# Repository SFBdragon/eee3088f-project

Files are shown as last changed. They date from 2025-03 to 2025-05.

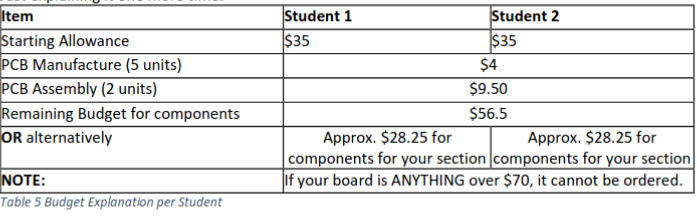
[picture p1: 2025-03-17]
notes/eee3088f-project/resources/budget-table.png

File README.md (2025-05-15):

# EEE3088F Project

> Power board for a micro-mouse designed for EEE3088F Engineering Design Principles @ UCT

#### Authors

_Team #69_
- Shaun Beautement
- Adedamola Yusuff

### Project Description

The board aims to meet the following requirements:
- Operate up to 4 motors bidirectionally 
    - Controls 2x brushed DC motors which could each draw 200mA @ 4.2V
    - Controls 2x motors at 500mA each.
- Monitor the battery using an INA219
- Charge the battery from USB supply
- Two charging modes the battery: IBAT = 200mA, or 600mA ±100mA
- Integrate USB C and get 9V out of the USB Host
- Provide 2x high-side external load switching with 5V regulated supply, drawing at most 1A each
- Provide a 3V3 5% accuracy (300mA max) and 5V Out 5% accuracy (1.5A max)
- Provide an ON/OFF switch.
    - OFF state: battery draw <30uA.
    - ON state: can provide your robot peak current of 2A.

The board is designed to be printable with PCBA for most components for under $70 with JLCPCB. As-is, the design costs about $50, not including the JST and 2x16 connector, which was provided to us.

The board is shaped to fit to and interface with
- [Justin Pead](https://ebe.uct.ac.za/department-electrical-engineering/contacts/justin-pead)'s micro-mouse (2025 version)
- a [1s1p LiPo battery](https://www.robotics.org.za/802540)
- a USB C cable (USB v2 and v3 should work) for charging

### Software

The schematic and PCB design is drafted in [KiCAD](https://www.kicad.org/), with metadata included for JLCPCB using [KiCAD JLCPCB Tools](https://github.com/Bouni/kicad-jlcpcb-tools).

Some prototype simulations in [LTspice](https://www.analog.com/en/resources/design-tools-and-calculators/ltspice-simulator.html) are included in `ltspice/`.

Some working notes are included under `notes/` and can be viewed in [Obsidian](https://obsidian.md/). But are best unseen.

### Usage Warning

It is not recommended to use this design as-is, as the board is incapable of delivering regulated supply voltages and driving motors.

With this design:
- There was a short from the buck-boosts' (TPS63020) VIN pins to GND, seemingly through the IC (without having powered the board). The cause is unclear at time of writing.
- The motor drivers were not operational. The cause is unclear at time of writing, and may have been a defieciency in the testing methodology.
- There are some capacitors with incorrect footprints.
- The USB C port is too far back on the board.

These have not been corrected for at time of writing, largely to preserve the state of the design for project submission.

### License 

CERN Open Hardware Licence Version 2 - Permissive

See [LICENSE.md](./LICENSE.md)

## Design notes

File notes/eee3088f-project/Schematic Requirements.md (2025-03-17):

+ A JST PH 2mm pin pitch connector for the battery. The battery will be tucked away between the motherboard PCB and the processor PCB.
+ A 2x16 (2.54mm pin pitch) pin header: It needs to fit onto the MM’s motherboard 2x16 2.54mm pitch connector with the correct pinout. Hint: be sure to pay attention to the alignment of the pins
+ The maximum dimensions for your board are 82 x 60 for it to fit under the motherboard PCB. Please note this even though JLC allows larger.
+ The shape of the board is an important consideration: If your board extends to any of the drill holes on the MB, your power board needs to use them for securing your PCB as the weight of the PCB will be too much for the connector alone.
+ The Motherboard dimensions arc radius is 80mm and the connectors centre is 15.3mm from the apex of the arc.

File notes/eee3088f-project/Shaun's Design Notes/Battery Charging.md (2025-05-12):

• Charge the battery from the 9V input pin (listed in the power pinout table).

• Have two charging modes for a higher and lower charging current for the battery (200mA, and approximately 600mA ±100mA from the battery perspective.

---

Input: 9V

Output: $V_{BAT}$ iff not charging, else nada

$I_{BAT}$ = 200mA - 600mA ($\pm 100$mA)

| Part | VIN MAX | IBAT MAX | Usable | Reason | JLC |
| --- | --- | --- | --- | --- | --- |
| TP5000 | | | No | Buck, Tiny Rs | |
| [TP4056](https://jlcpcb.com/api/file/downloadByFileSystemAccessId/8588879072461508608) | 8V | 1A | Yes | Lots of features! | [link](https://jlcpcb.com/partdetail/17264-TP4056_42ESOP8/C16581) |
| TP4057 | | 0.5A ! | No | | |
| [TP4054](https://www.laskakit.cz/user/related_files/tp4054.pdf) | 9V | 0.8A | Yes | | [link](https://jlcpcb.com/partdetail/33539-TP4054_42SOT25R/C32574) |
| MAX8903 | | | No | Low stock, linear instead of buck (too much power dis.) | |
| [FM4057](https://jlcpcb.com/api/file/downloadByFileSystemAccessId/8588918019694845952) | | | Yes | Loader fee! | [link](https://jlcpcb.com/partdetail/Shenzhen_FumanElec-FM4057S52/C841288) |
| [SLM6305](https://jlcpcb.com/partdetail/solaic-SLM6305/C711584) | | | No | Buck, Tiny Rs | [link](https://jlcpcb.com/partdetail/solaic-SLM6305/C711584) |
| [TP5100](https://jlcpcb.com/api/file/downloadByFileSystemAccessId/8588884095233769472) | | | No | Buck, Tiny Rs | [link](https://jlcpcb.com/partdetail/solaic-SLM6305/C711584) |
| BQ24610 | | | No | Buck, Tiny Rs, Seriously overkill (2x costs $1.7) | |
| | | | | | |
![[Pasted image 20250424195714.png]]
XL1059 (buck converter IC, basic)
+FM407S42 (linear battery management IC for charging control)
+MOSFET switching the resistance

Ignore all of this, I went with something else...

SLM6305 calculations:

$R_{s,eff,fast} = \frac{0.0667}{I_{BAT}} =  \frac{0.0667}{0.6} = 111m\Omega$
$R_{s,eff,slow} = \frac{0.0667}{I_{BAT}} = \frac{0.0667}{0.2} = 333.5m\Omega$

We need more resistance when FAST is LOW.

MOSFET gate and source are roughly 4.2V
Requires logic low to turn on.
So P channel MOSFET

$R_{s,always} = R_{s,eff,fast} - R_{DS,on} = 0.111 - (0.048||R_{s,bypass})$
$R_{s,bypass} = R_{s,eff,slow} - R_{s,always} = 0.3335 - R_{s,always}$

$R_{s,always} = 70.4m\Omega$
$R_{s,bypass} = 263.1m\Omega$

We need to invert the input.

$R_{s,slow} = R_{s,eff,slow} - R_{DS,on} =$

---

Buck converter

https://www.ti.com/lit/ds/symlink/tps5430.pdf?ts=1742809000146

$$L_{MIN} = \frac{V_{OUT(MAX)}(V_{IN(MAX)}-V_{OUT})}{V_{IN(MAX)} K_{IND} I_{OUT} F_{SW}} = \frac{5(9-5)}{9*0.3*0.8*500000} = 18.5\mu H$$

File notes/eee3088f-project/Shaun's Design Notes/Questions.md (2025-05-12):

Should we worry about rotations

---

Must the INA219 be powered even when the system is "off" 

---

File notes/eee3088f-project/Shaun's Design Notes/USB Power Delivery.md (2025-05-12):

• Integrate USB C and get 9V out of the USB Host

---

https://www.usb.org/sites/default/files/USB%20Type-C%20Spec%20R2.0%20-%20August%202019.pdf

USB PD 
https://jlcpcb.com/parts/2nd/Power_Management_(PMIC)/USB_PD_1639

Relevant pins:

| Pin No | Name | Purpose |
| --- | --- | --- |
| 13 | `FAST_CHARGE_CTRL` | Logic-level signal for fast charge ON/OFF |
| 14 | `BATTERY` | Connect to VBAT+ |
| 19 | `GND` | Connect to GND |
| 22 | `HV` | Connect to 9V from USB PD |

CH224K
https://jlcpcb.com/partdetail/wch_jiangsu_Qin_heng-CH224K/C970725
??????????
https://www.laskakit.cz/user/related_files/ch224ds1.pdf
YESSSSSSSSSSSSSSSSS

ACTUALLY NEEDS MAX12 AND THERE'S NONE AVAILABLE
https://jlcpcb.com/partdetail/Injoinic-IP2721/C603176
https://jlcpcb.com/api/file/downloadByFileSystemAccessId/8588893818120769536
IP2721
Can request 9V directly without uC

https://www.ti.com/lit/ds/symlink/tusb320.pdf?ts=1745478480336
Not sure if this actually does what I need

https://jlcpcb.com/api/file/downloadByFileSystemAccessId/8589839603521269760
same deal

https://www.nxp.com/docs/en/data-sheet/PTN5150A.pdf
?

https://www.st.com/resource/en/datasheet/stusb4500.pdf
Definitely can do what I need.
$1.78 https://jlcpcb.com/partdetail/Stmicroelectronics-STUSB4500QTR/C2678061
NOT BY DEFAULT

https://www.ti.com/lit/ds/symlink/tps25730.pdf?ts=1742514233405
also seems stupidly overkill

**FUSB302B**
https://jlcpcb.com/partdetail/Onsemi-FUSB302BMPX/C132291
not passively usable?

USB C connector
**NEED TO BUY**

Battery connector
https://www.robotics.org.za/JST-PH-2P-90?search=jst
no need to buy

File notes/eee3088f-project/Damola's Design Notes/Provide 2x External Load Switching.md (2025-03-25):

Provide 2x External Load Switching at 1A each (High Side connected to your 5V)

## Thoughts:
I'm struggling to even interpret this

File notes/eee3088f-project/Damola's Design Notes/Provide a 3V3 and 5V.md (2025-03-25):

Provide a 3V3 5% accuracy (300mA max) and 5V Out 5% accuracy (1.5A max)

## Thoughts:
Just use voltage regulators, no?
Indeed, no.

## Decisions:

$V_{out}=V_{ref}\times(1+\frac{R_{3}}{R_{4}})$ 
$\frac{V_{out}}{V_{ref}}-1=\frac{R_{A}}{R_{B}}$

$V_{ref}=0.6V$ (typical)

$V_{out1}=5V$
$V_{out2}=3V3$

### Resistor Options for 5V (Boost Converter):

$\frac{V_{out1}}{0.6}-1=\frac{R_{3}}{R_{4}}$
$\frac{5}{0.6}-1=\frac{R_{3}}{R_{4}}$
$7.33=\frac{R_{3}}{R_{4}}$

$R_{4}=1000\Omega$
$R_3=6800\Omega+510\Omega$  $(7.31)$

$R_{4}=1300\Omega$
$R_3=9100\Omega+510\Omega$  $(7.39)$

$R_{4}=1800\Omega$
$R_3=13000\Omega+200\Omega$  $(7.33)$

The one above looks very good but will the $200\Omega$ survive the current?
$R_4=1800\Omega$ 
$R_3=11000\Omega+2200\Omega$  $(7.33)$ is better. (This became $R_3$ and $R_7$)

## Resistor Options for 5V (Buck-Boost Converter):

$R_1=R_2\times(\frac{V_{OUT}}{V_{FB}}-1)$
$\frac{R_1}{R_2}=(\frac{V_{OUT}}{V_{FB}}-1)$
$V_{FB}=0.5V$
$V_{OUT}=5V$
$\frac{R_1}{R_2}=\frac{5}{0.5}-1$
$\frac{R_1}{R_2}=9$
$R_1=(4.3\times10^{x})+(4.7\times10^{x})$
$R_2=1.0\times10^{x}$

The current through the resistive divider should be about 100 times greater than the
current into the FB pin.

The typical current into the FB pin is 0.01μA and the voltage across the resistor between
FB and GND, R2, is typically 500 mV. Based on these two values, the recommended value for R2 should be lower than 500kΩ (Because $500k\Omega=\frac{500mV}{0.01μA\times100}$).

Therefore, we can choose:
$R_2=100k$
and $R_1=430k\Omega+470k\Omega$

## Choosing an inductor for the 5V Buck-Boost converter

The larger the inductor value, the smaller the inductor ripple current and the lower the conduction losses of the converter. Conversely, larger inductor values cause a slower load transient response

The datasheet tells me what to choose.

0.63

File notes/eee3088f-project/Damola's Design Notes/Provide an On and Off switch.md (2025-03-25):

Provide an ON/OFF switch. OFF state: battery draw <30uA. ON state: can provide your robot peak current of 2A. The switch needs to shut down 5V and 3V3.

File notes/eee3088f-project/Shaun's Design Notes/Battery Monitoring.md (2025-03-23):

Place an INA219 for monitoring the battery on the I2C Bus and configure it correctly with respect to the hardware (cannot have BOTH A0 AND A1 on GND)

---

TODO

| Pin No | Name | Purpose |
| --- | --- | --- |
| 16 | `I2C1_SCL`  | I2C communication with current/voltage/power monitor (clock) |
| 17 | `I2C1_SDA`  | I2C communication with current/voltage/power monitor (data)  |

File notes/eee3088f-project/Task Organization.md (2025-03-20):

### Shaun

• Place an INA219 for monitoring the battery on the I2C Bus and configure it correctly with
respect to the hardware (cannot have BOTH A0 AND A1 on GND)

• Have two charging modes for a higher and lower charging current for the battery (200mA, and approximately 600mA ±100mA from the battery perspective.

• Integrate USB C and get 9V out of the USB Host

• Charge the battery from the 9V input pin (listed in the power pinout table).

### Damola

• Operate up to 4 motors bidirectionally with the pins available to you (listed in the power pinout table). You will need to control 2x brushed DC motors which could each draw 200mA at the highest voltage of a 1S1P battery (the battery is further specified in the battery section).
The other 2x motors are for the auxiliary connection and need to operate 500mA each.

• Provide a 3V3 5% accuracy (300mA max) and 5V Out 5% accuracy (1.5A max)

• Provide an ON/OFF switch. OFF state: battery draw <30uA. ON state: can provide your robot peak current of 2A. The switch needs to shut down 5V and 3V3.

• Provide 2x External Load Switching at 1A each (High Side connected to your 5V)

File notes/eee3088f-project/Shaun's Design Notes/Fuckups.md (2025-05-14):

C4, C6, C8, C14, C15, C16, C18, C22
+3 others

| | C4 | C6 | C8 | C14 | C15  | C16  | C18  | C22 |
| --- | ---- | ---- | ---- | ----- | ---- | ---- | ---- | ----- |
| Cap | 10nF | 22uF | 10nF | 100nF | 22uF | 22u  | 22u  | 100nF |
| Board Foot | 0402 | 0805 | 0402 | 0603  | 0805 | 0805 | 0805 | 0603  |
| Ordered | 0805 | 0805 | 0805 | 0402  | 0603 | 0805 | 0805 | 0402  |

![[Pasted image 20250404172052.png]]

![[Pasted image 20250404171827.png]]

![[Pasted image 20250404171915.png]]

![[Pasted image 20250404171948.png]]

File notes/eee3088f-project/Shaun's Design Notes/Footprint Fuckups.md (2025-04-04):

C4, C8, C14, C15, C22

| | C4 | C8 | C14 | C15  | C22 |
| --- | ---- | ---- | ----- | ---- | ----- |
| Cap | 10nF | 10nF | 100nF | 22uF | 100nF |
| Board Foot | 0402 | 0402 | 0603  | 0805 | 0603  |
| Ordered | 0805 | 0805 | 0402  | 0603 | 0402  |

![[Pasted image 20250404172052.png]]

![[Pasted image 20250404171827.png]]

![[Pasted image 20250404171915.png]]

![[Pasted image 20250404171948.png]]

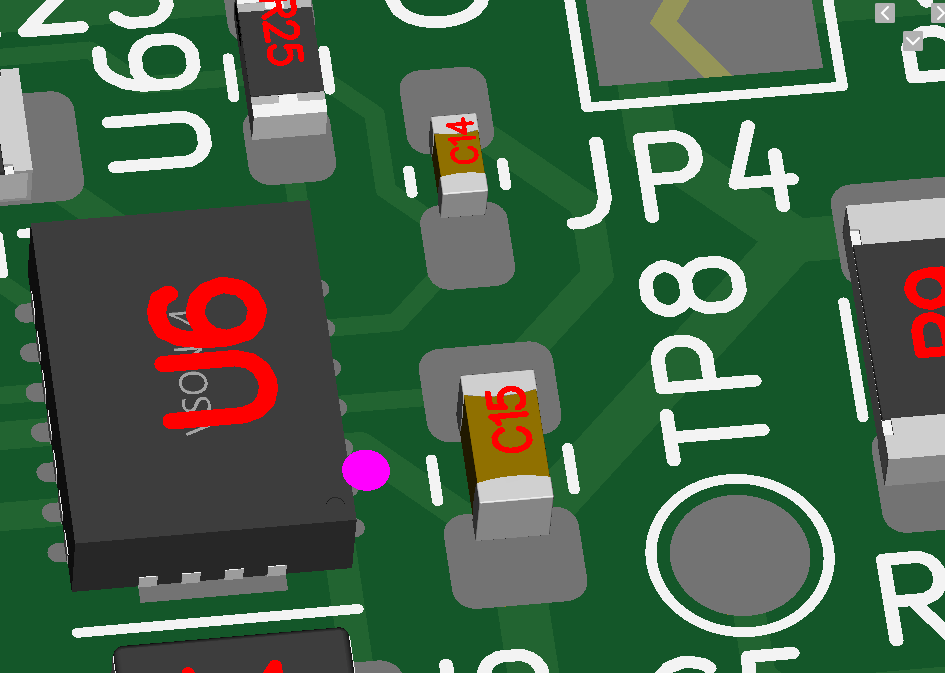
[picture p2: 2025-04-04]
notes/eee3088f-project/Shaun's Design Notes/resources/Pasted image 20250404171827.png

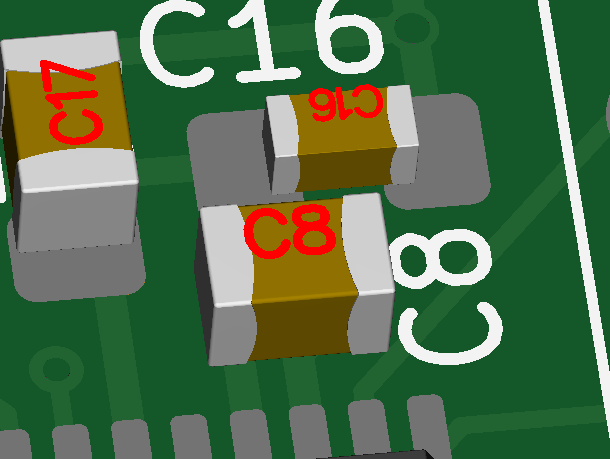
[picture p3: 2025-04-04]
notes/eee3088f-project/Shaun's Design Notes/resources/Pasted image 20250404171915.png

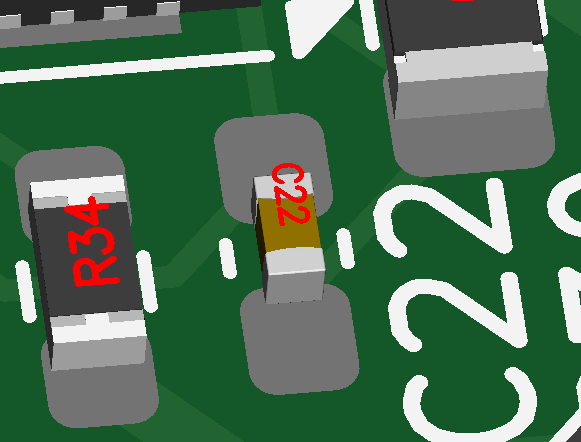
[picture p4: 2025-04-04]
notes/eee3088f-project/Shaun's Design Notes/resources/Pasted image 20250404172052.png

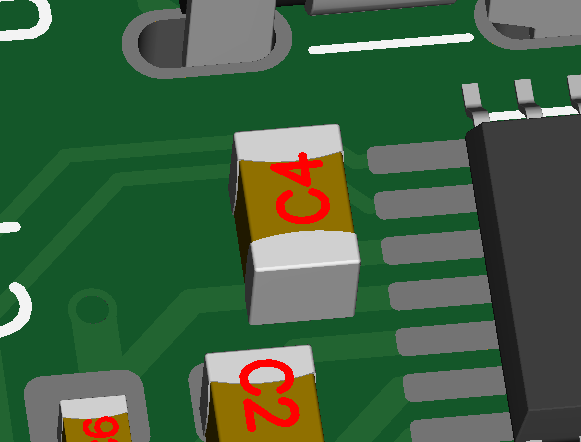
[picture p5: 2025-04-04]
notes/eee3088f-project/Shaun's Design Notes/resources/Pasted image 20250404171948.png

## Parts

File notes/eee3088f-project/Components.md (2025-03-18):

> Before we break this down, please note that when ordering the PCBs you will ONLY NEED TO POPULATE the USB-C connectors. To be clear, we will provide you with the pin headers and JST connectors described in the power subsystem section. You will still need to provide the footprint on your PCB but will not populate them in your BOM.

> Now to truly understand the difficulty of each task, you each have a total of $35 to have your board manufactured. That is 5x PCBs made @ $4, 2x PCBs populated @ $9.50 and then your component costs.

> `$13.5` is being used to manufacture a standard sized simple board. So, you have `$(35*2) – $13.5` worth of components on the sum of your board section. $56.5 on components. Pay attention to extended parts…

![[budget-table.png]]

Some special components we should probably strongly consider:
- H Bridge Drivers
- Voltage regulators (need Low Drop Out (LDO), consider linear (low efficiency, simply) vs switched-mode (higher efficiency, more complicated))

Shaun's components

| Component | Unit Cost | N |
| --- | --- | --- |
| | | |

Damola's components

| Component | Unit Cost | N |
| --- | --- | --- |
| | | |

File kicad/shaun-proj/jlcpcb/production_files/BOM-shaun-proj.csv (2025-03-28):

Comment | Designator | Footprint | LCSC | Quantity
INA219AxD | U3 | SOIC-8_3.9x4.9mm_P1.27mm | C138706 | 1
100n | C10 | C_0603_1608Metric_Pad1.08x0.95mm_HandSolder | C14663 | 1
AO3401A | Q1,Q3,Q6 | SOT-23 | C15127 | 3
10n | C9 | C_0402_1005Metric_Pad0.74x0.62mm_HandSolder | C15195 | 1
0.1µF | C14,C22 | C_0603_1608Metric_Pad1.08x0.95mm_HandSolder | C1525 | 2
TPS63020DSJR | U6,U8 | DAMOLA_VSON-14-1EP_3.4x4.4mm_P0.5mm_EP1.6x4.2mm | C15483 | 2
10u | C11 | C_0805_2012Metric_Pad1.18x1.45mm_HandSolder | C15850 | 1
TP4056-42-ESOP8 | U5 | SOIC-8-1EP_3.9x4.9mm_P1.27mm_EP2.41x3.3mm_ThermalVias | C16581 | 1
USB_C_Receptacle_USB2.0_16P | J1 | USB_C_Receptacle_G-Switch_GT-USB-7010ASV_MOD | C165948 | 1
0.01µF | C4,C8 | C_0402_1005Metric_Pad0.74x0.62mm_HandSolder | C1710 | 2
120k | R27 | R_0805_2012Metric_Pad1.20x1.40mm_HandSolder | C17436 | 1
180k | R24,R30 | R_0805_2012Metric_Pad1.20x1.40mm_HandSolder | C17501 | 2
10u | C3,C5 | C_0603_1608Metric_Pad1.08x0.95mm_HandSolder | C19702 | 2
AO3400A | Q2,Q4,Q5 | SOT-23 | C20917 | 3
1k | R14,R15,R17 | R_0603_1608Metric_Pad0.98x0.95mm_HandSolder | C21190 | 3
RED LED | D1 | LED_0603_1608Metric_Pad1.05x0.95mm_HandSolder | C2286 | 1
1M | R18,R23,R25,R3,R34,R5 | R_0603_1608Metric_Pad0.98x0.95mm_HandSolder | C22935 | 6
GREEN LED | D2,D4 | LED_0805_2012Metric_Pad1.15x1.40mm_HandSolder | C2297 | 2
3.3k | R12,R13,R20,R21 | R_0603_1608Metric_Pad0.98x0.95mm_HandSolder | C22978 | 4
3.9k | R7 | R_0603_1608Metric | C23018 | 1
6.8K | R1 | R_0603_1608Metric | C23212 | 1
SS14 | D5 | D_SMA | C2480 | 1
1 | R16,R29,R32,R33,R36,R8 | R_0805_2012Metric_Pad1.20x1.40mm_HandSolder | C25271 | 6
100m | R19,R26,R28,R31,R35,R9 | R_1206_3216Metric_Pad1.30x1.75mm_HandSolder | C25334 | 6
220u | C12,C13,C20 | CP_Elec_6.3x7.7 | C25503905 | 3
10k | R10,R11,R2,R6 | R_0603_1608Metric_Pad0.98x0.95mm_HandSolder | C25804 | 4
22u | L3 | L_SXN_SMDRI125 | C2924827 | 1
2.2µF | C17,C2 | C_0805_2012Metric_Pad1.18x1.45mm_HandSolder | C377773 | 2
1.5M | R22 | R_0603_1608Metric_Pad0.98x0.95mm_HandSolder | C4172 | 1
2k | R4 | R_0603_1608Metric | C4190 | 1
DRV8833PWPR | U4,U7 | HTSSOP-16-1EP_4.4x5mm_P0.65mm_EP3.4x5mm_Mask2.46x2.31mm_ThermalVias | C50506 | 2
1µH | L4,L5,L6 | L_1008_2520Metric_Pad1.43x2.20mm_HandSolder | C5179444 | 3
1u | C1 | C_0402_1005Metric_Pad0.74x0.62mm_HandSolder | C52923 | 1
22µF | C15,C16,C18,C6 | C_0805_2012Metric_Pad1.18x1.45mm_HandSolder | C59461 | 4
SW_SPDT | SW2 | SS-12D11G3R | C843362 | 1
CH224K | U1 | SSOP-10-1EP_3.9x4.9mm_P1mm_EP2.1x3.3mm_ThermalVias | C970725 | 1
TPS5430DDA | U2 | SOIC-8-1EP_3.9x4.9mm_P1.27mm_EP2.514x3.2mm | C9864 | 1

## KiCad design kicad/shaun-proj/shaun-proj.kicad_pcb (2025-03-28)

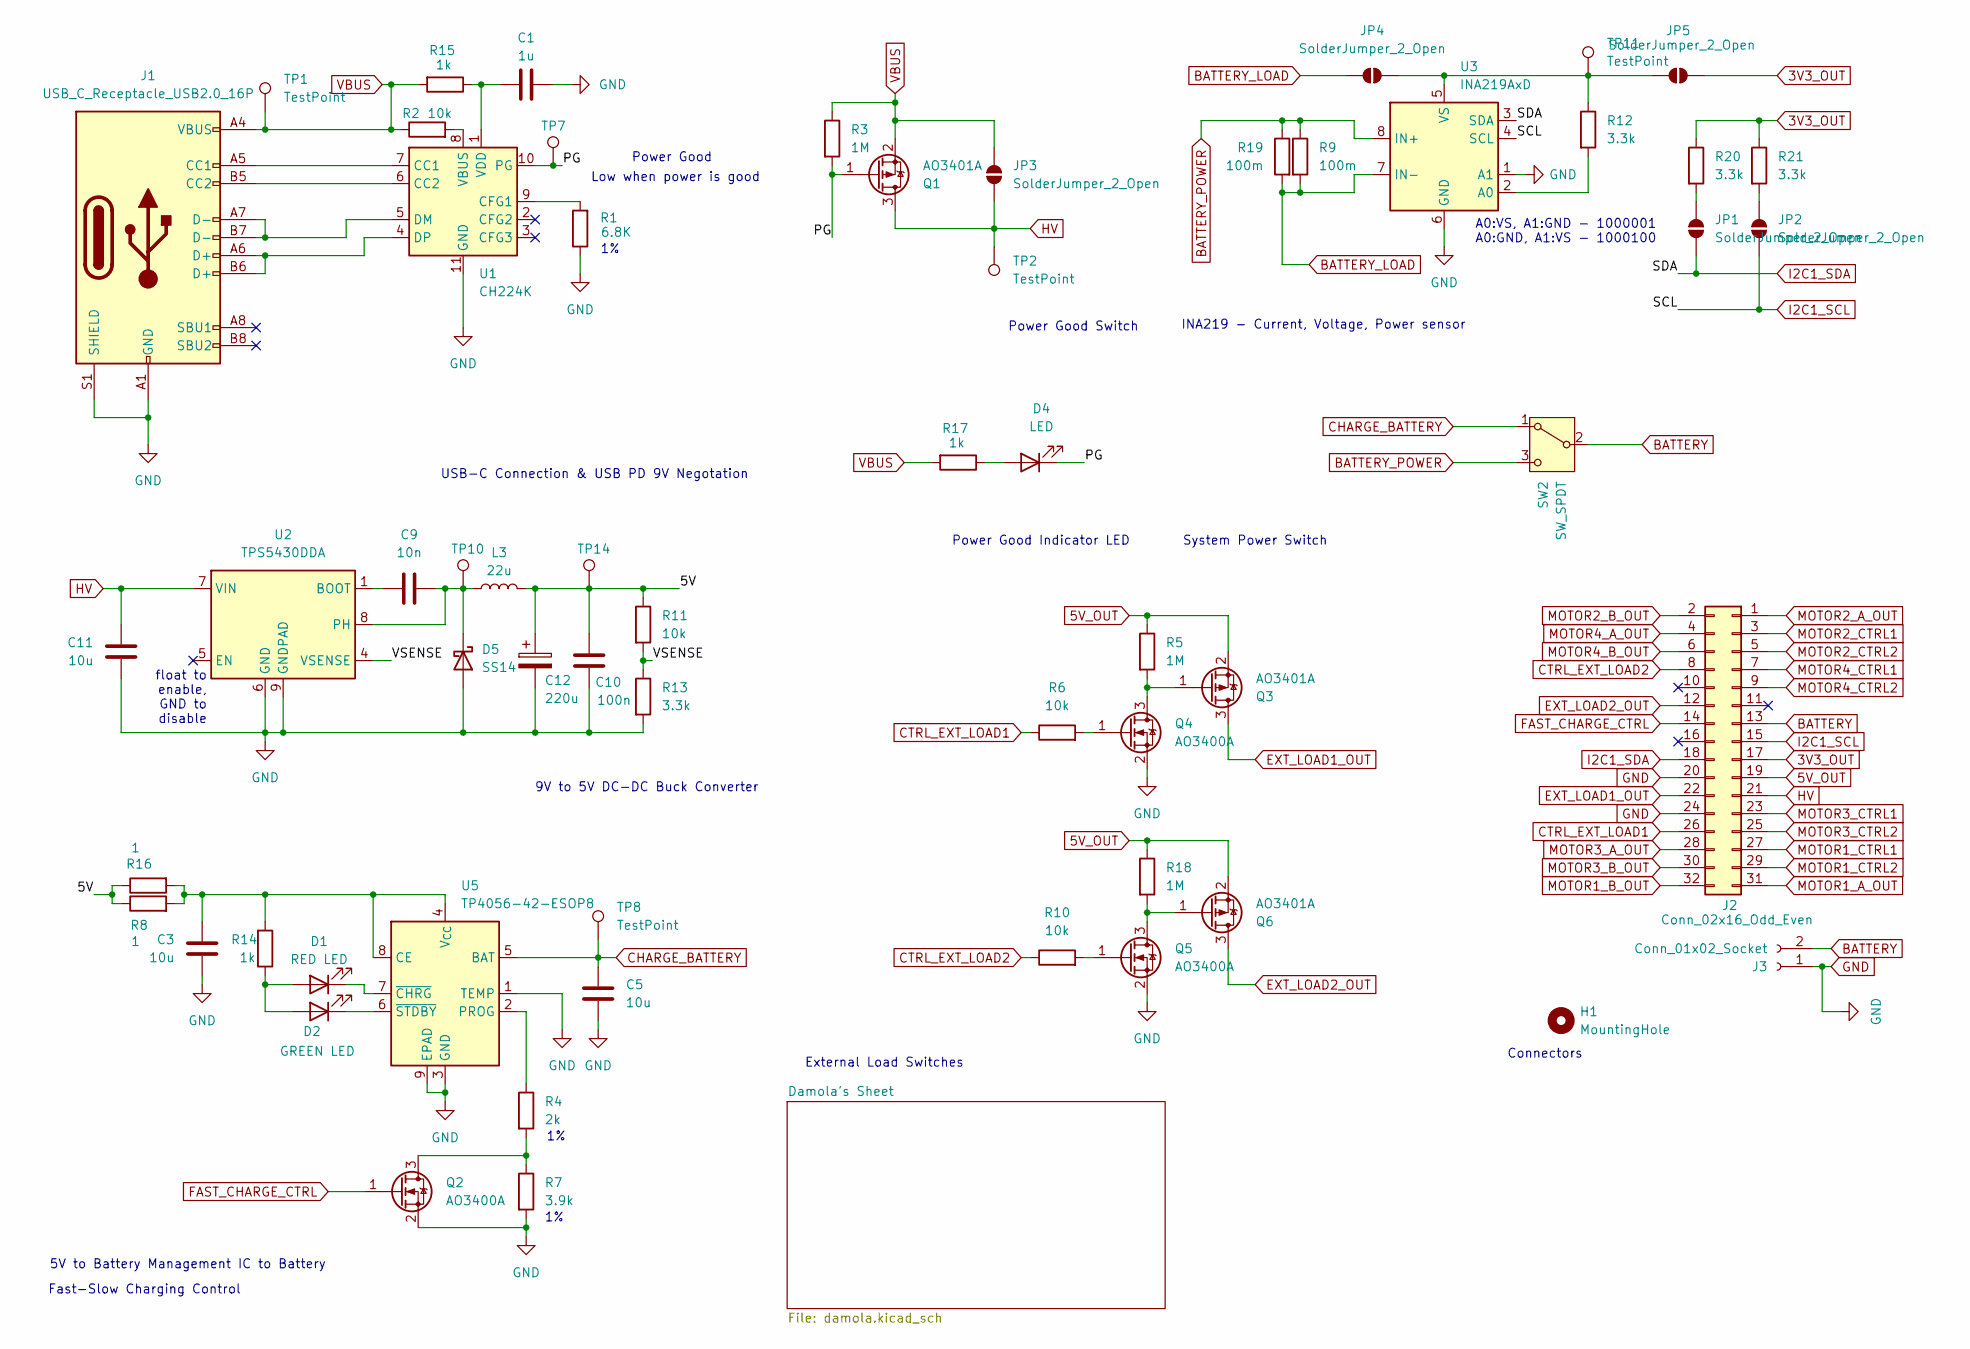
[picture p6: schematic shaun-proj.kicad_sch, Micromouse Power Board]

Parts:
C1: 1u; C_0402_1005Metric_Pad0.74x0.62mm_HandSolder
C3: 10u; C_0603_1608Metric_Pad1.08x0.95mm_HandSolder
C5: 10u; C_0603_1608Metric_Pad1.08x0.95mm_HandSolder; LCSC C19702
C9: 10n; C_0402_1005Metric_Pad0.74x0.62mm_HandSolder; LCSC C15195
C10: 100n; C_0603_1608Metric_Pad1.08x0.95mm_HandSolder
C11: 10u; C_0805_2012Metric_Pad1.18x1.45mm_HandSolder
C12: 220u; CP_Elec_6.3x7.7; LCSC C25503905
D1: RED LED; LED_0603_1608Metric_Pad1.05x0.95mm_HandSolder
D2: GREEN LED; LED_0805_2012Metric_Pad1.15x1.40mm_HandSolder
D4: LED; LED_0805_2012Metric_Pad1.15x1.40mm_HandSolder
D5: SS14; D_SMA
H1: MountingHole; MountingHole_3.2mm_M3
J1: USB_C_Receptacle_USB2.0_16P; USB_C_Receptacle_G-Switch_GT-USB-7010ASV_MOD; LCSC C165948
J2: Conn_02x16_Odd_Even; PinHeader_2x16_P2.54mm_Vertical
J3: Conn_01x02_Socket; JST_PH_S2B-PH-K_1x02_P2.00mm_Horizontal
JP1, JP2, JP3, JP4, JP5: SolderJumper_2_Open; SolderJumper-2_P1.3mm_Open_TrianglePad1.0x1.5mm
L3: 22u; L_SXN_SMDRI125
Q1, Q3, Q6: AO3401A; SOT-23; JLCPCB no C15127
Q2: AO3400A; SOT-23
Q4, Q5: AO3400A; SOT-23; LCSC C20917
R1: 6.8K; R_0603_1608Metric
R2, R6, R10, R11: 10k; R_0603_1608Metric_Pad0.98x0.95mm_HandSolder
R3, R5, R18: 1M; R_0603_1608Metric_Pad0.98x0.95mm_HandSolder
R4: 2k; R_0603_1608Metric
R7: 3.9k; R_0603_1608Metric
R8, R16: 1; R_0805_2012Metric_Pad1.20x1.40mm_HandSolder
R9, R19: 100m; R_1206_3216Metric_Pad1.30x1.75mm_HandSolder
R12, R13, R20, R21: 3.3k; R_0603_1608Metric_Pad0.98x0.95mm_HandSolder
R14, R15, R17: 1k; R_0603_1608Metric_Pad0.98x0.95mm_HandSolder
SW2: SW_SPDT; SS-12D11G3R
TP1, TP2, TP7, TP8, TP10, TP11, TP14: TestPoint; TestPoint_Pad_D1.5mm
U1: CH224K; SSOP-10-1EP_3.9x4.9mm_P1mm_EP2.1x3.3mm_ThermalVias; LCSC C970725
U2: TPS5430DDA; SOIC-8-1EP_3.9x4.9mm_P1.27mm_EP2.514x3.2mm; LCSC C9864
U3: INA219AxD; SOIC-8_3.9x4.9mm_P1.27mm
U5: TP4056-42-ESOP8; SOIC-8-1EP_3.9x4.9mm_P1.27mm_EP2.41x3.3mm_ThermalVias; LCSC C16581

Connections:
3V3_OUT: J2.17, JP5.1 (A), R20.1, R21.1; also elsewhere on the board
5V_OUT: J2.19, Q3.2 (S), Q6.2 (S), R5.1, R18.1; also elsewhere on the board
/5V: C10.1, C12.1, L3.2, R8.1, R11.1, R16.1, TP14.1
/PG: D4.1 (K), Q1.1 (G), R3.2, TP7.1, U1.10 (PG)
/VSENSE: R11.2, R13.1, U2.4 (VSENSE)
BATTERY: J2.13, J3.2, SW2.2 (B)
BATTERY_LOAD: JP4.2 (B), R9.2, R19.2, U3.7 (IN-); also elsewhere on the board
BATTERY_POWER: R9.1, R19.1, SW2.3 (C), U3.8 (IN+)
CHARGE_BATTERY: C5.1, SW2.1 (A), TP8.1, U5.5 (BAT)
CTRL_EXT_LOAD1: J2.26, R6.1
CTRL_EXT_LOAD2: J2.8, R10.1
EXT_LOAD1_OUT: J2.22, Q3.3 (D)
EXT_LOAD2_OUT: J2.12, Q6.3 (D)
FAST_CHARGE_CTRL: J2.14, Q2.1 (G)
GND: C1.2, C3.2, C5.2, C10.2, C11.2, C12.2, D5.2 (A), J1.A1 (GND), J1.A12 (GND), J1.B1 (GND), J1.B12 (GND), J1.S1 (SHIELD), J2.20, J2.24, J3.1, Q2.2 (S), Q4.2 (S), Q5.2 (S), R1.1, R7.2, R13.2, U1.11 (GND), U2.6 (GND), U2.9 (GNDPAD), U3.1 (A1), U3.6 (GND), U5.1 (TEMP), U5.3 (GND), U5.9 (EPAD); also elsewhere on the board
HV: C11.1, J2.21, JP3.1 (A), Q1.3 (D), TP2.1, U2.7 (VIN)
I2C1_SCL: J2.15, JP2.1 (A), U3.4 (SCL)
I2C1_SDA: J2.18, JP1.1 (A), U3.3 (SDA)
MOTOR1_A_OUT: J2.31; also elsewhere on the board
MOTOR1_B_OUT: J2.32; also elsewhere on the board
MOTOR1_CTRL1: J2.27; also elsewhere on the board
MOTOR1_CTRL2: J2.29; also elsewhere on the board
MOTOR2_A_OUT: J2.1; also elsewhere on the board
MOTOR2_B_OUT: J2.2; also elsewhere on the board
MOTOR2_CTRL1: J2.3; also elsewhere on the board
MOTOR2_CTRL2: J2.5; also elsewhere on the board
MOTOR3_A_OUT: J2.28; also elsewhere on the board
MOTOR3_B_OUT: J2.30; also elsewhere on the board
MOTOR3_CTRL1: J2.23; also elsewhere on the board
MOTOR3_CTRL2: J2.25; also elsewhere on the board
MOTOR4_A_OUT: J2.4; also elsewhere on the board
MOTOR4_B_OUT: J2.6; also elsewhere on the board
MOTOR4_CTRL1: J2.7; also elsewhere on the board
MOTOR4_CTRL2: J2.9; also elsewhere on the board
unnamed: D1.2 (A), D2.2 (A), R14.1
unnamed: D1.1 (K), U5.7 (~CHRG)
unnamed: D2.1 (K), U5.6 (~STDBY)
unnamed: D4.2 (A), R17.1
unnamed: C9.2, D5.1 (K), L3.1, TP10.1, U2.8 (PH)
unnamed: J1.A5 (CC1), U1.7 (CC1)
unnamed: J1.B5 (CC2), U1.6 (CC2)
unnamed: JP1.2 (B), R20.2
unnamed: JP2.2 (B), R21.2
unnamed: JP4.1 (A), JP5.2 (B), R12.1, TP11.1, U3.5 (VS)
unnamed: Q2.3 (D), R4.2, R7.1
unnamed: Q3.1 (G), Q4.3 (D), R5.2
unnamed: Q4.1 (G), R6.2
unnamed: Q5.3 (D), Q6.1 (G), R18.2
unnamed: Q5.1 (G), R10.2
unnamed: R1.2, U1.9 (CFG1)
unnamed: J1.A7 (D-), J1.B7 (D-), U1.5 (DM)
unnamed: J1.A6 (D+), J1.B6 (D+), U1.4 (DP)
unnamed: R2.2, U1.8 (VBUS)
unnamed: C1.1, R15.1, U1.1 (VDD)
unnamed: C9.1, U2.1 (BOOT)
unnamed: R12.2, U3.2 (A0)
unnamed: C3.1, R8.2, R14.2, R16.2, U5.4 (V_{CC}), U5.8 (CE)
unnamed: R4.1, U5.2 (PROG)
VBUS: J1.A4 (VBUS), J1.A9 (VBUS), J1.B4 (VBUS), J1.B9 (VBUS), JP3.2 (B), Q1.2 (S), R2.1, R3.1, R15.2, R17.2, TP1.1

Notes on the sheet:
float to enable, GND to disable
5V to Battery Management IC to Battery
Low when power is good
Connectors
INA219 - Current, Voltage, Power sensor
External Load Switches
Power Good Switch
Power Good
USB-C Connection & USB PD 9V Negotation
9V to 5V DC-DC Buck Converter
A0:VS, A1:GND - 1000001 A0:GND, A1:VS - 1000100
Fast-Slow Charging Control
Power Good Indicator LED
System Power Switch

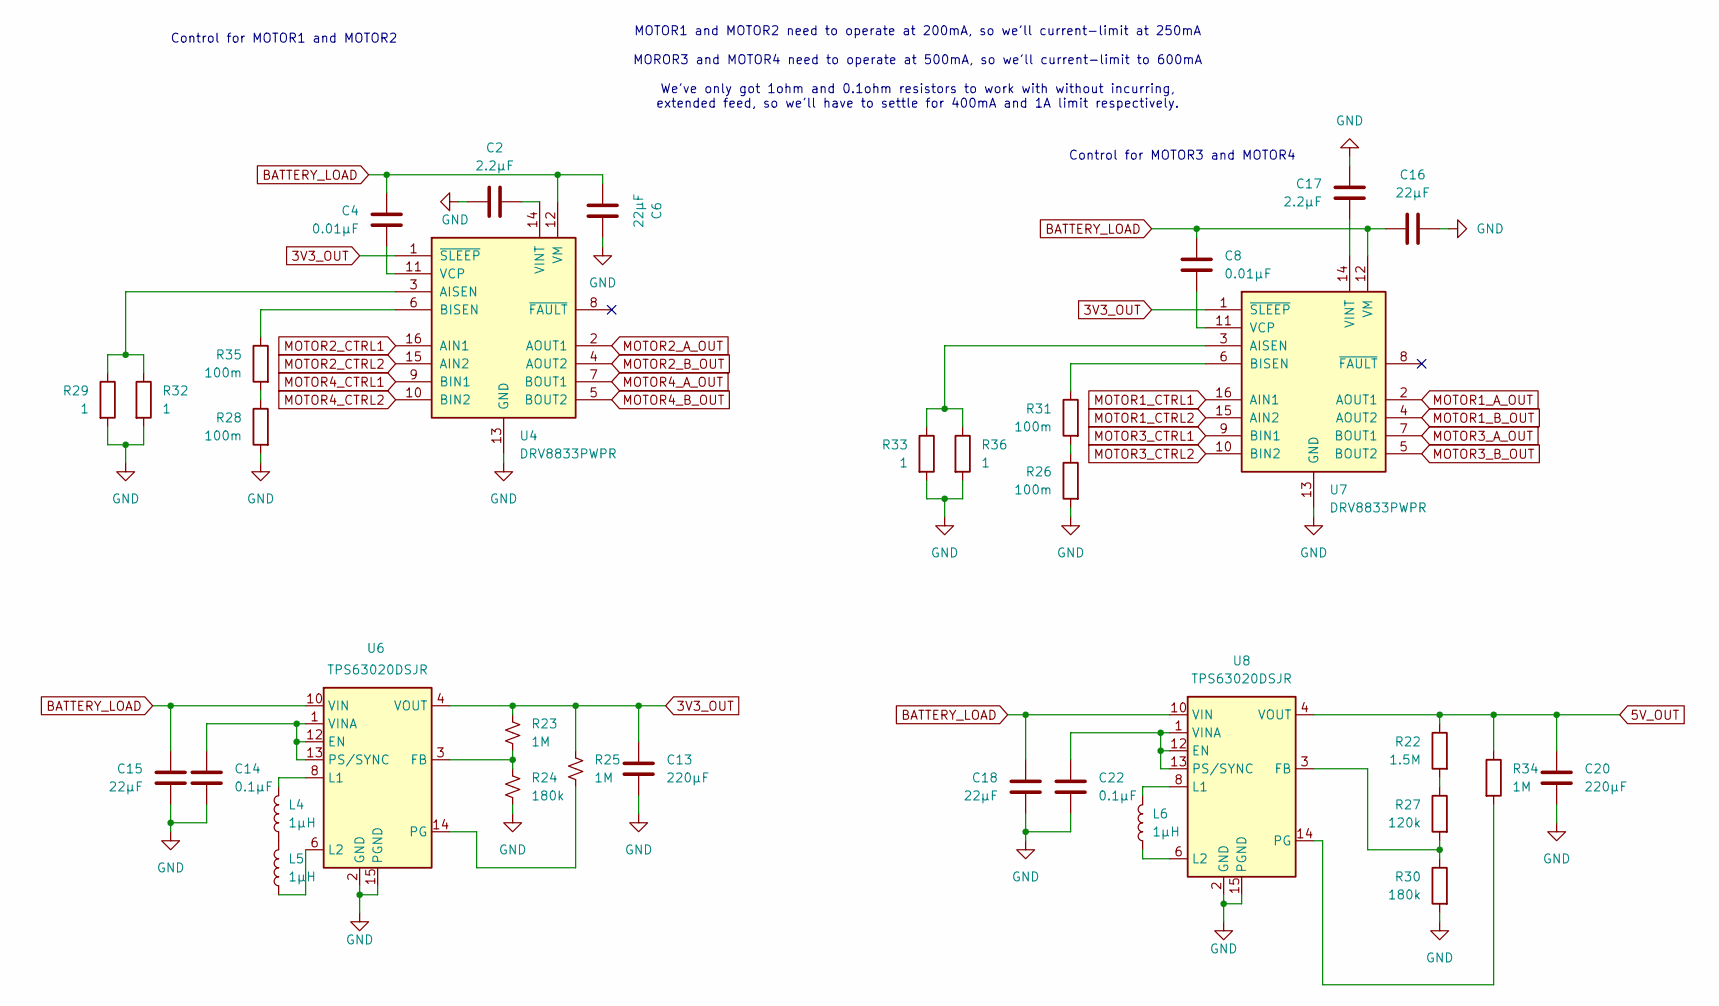
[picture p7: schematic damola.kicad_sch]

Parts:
C2, C17: 2.2µF; C_0805_2012Metric_Pad1.18x1.45mm_HandSolder
C4, C8: 0.01µF; C_0402_1005Metric_Pad0.74x0.62mm_HandSolder; LCSC C1710
C6, C15, C16: 22µF; C_0805_2012Metric_Pad1.18x1.45mm_HandSolder; LCSC C59461
C13, C20: 220µF; CP_Elec_6.3x7.7
C14, C22: 0.1µF; C_0603_1608Metric_Pad1.08x0.95mm_HandSolder; LCSC C1525
C18: 22µF; C_0805_2012Metric_Pad1.18x1.45mm_HandSolder
L4, L5, L6: 1µH; L_1008_2520Metric_Pad1.43x2.20mm_HandSolder; LCSC C1042
R22: 1.5M; R_0603_1608Metric_Pad0.98x0.95mm_HandSolder
R23, R25, R34: 1M; R_0603_1608Metric_Pad0.98x0.95mm_HandSolder; LCSC C22935
R24, R30: 180k; R_0805_2012Metric_Pad1.20x1.40mm_HandSolder
R26, R28, R31, R35: 100m; R_1206_3216Metric_Pad1.30x1.75mm_HandSolder
R27: 120k; R_0805_2012Metric_Pad1.20x1.40mm_HandSolder
R29, R32, R33, R36: 1; R_0805_2012Metric_Pad1.20x1.40mm_HandSolder
U4: DRV8833PWPR; HTSSOP-16-1EP_4.4x5mm_P0.65mm_EP3.4x5mm_Mask2.46x2.31mm_The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; LCSC C50506
U6, U8: TPS63020DSJR; DAMOLA_VSON-14-1EP_3.4x4.4mm_P0.5mm_EP1.6x4.2mm; LCSC C15483
U7: DRV8833PWPR; HTSSOP-16-1EP_4.4x5mm_P0.65mm_EP3.4x5mm_Mask2.46x2.31mm_The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

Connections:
3V3_OUT: C13.1, R23.1, R25.1, U4.1 (~SLEEP), U6.4 (VOUT), U7.1 (~SLEEP); also elsewhere on the board
5V_OUT: C20.1, R22.1, R34.1, U8.4 (VOUT); also elsewhere on the board
BATTERY_LOAD: C4.1, C6.2, C8.1, C15.1, C16.2, C18.1, U4.12 (VM), U6.10 (VIN), U7.12 (VM), U8.10 (VIN); also elsewhere on the board
GND: C2.1, C6.1, C13.2, C14.2, C15.2, C16.1, C17.2, C18.2, C20.2, C22.2, R24.2, R26.2, R28.2, R29.2, R30.2, R32.2, R33.2, R36.2, U4.13 (GND), U4.17 (GND), U6.2 (GND), U6.11 (PGND), U6.15 (PGND), U7.13 (GND), U7.17 (GND), U8.2 (GND), U8.11 (PGND), U8.15 (PGND); also elsewhere on the board
MOTOR1_A_OUT: U7.2 (AOUT1); also elsewhere on the board
MOTOR1_B_OUT: U7.4 (AOUT2); also elsewhere on the board
MOTOR1_CTRL1: U7.16 (AIN1); also elsewhere on the board
MOTOR1_CTRL2: U7.15 (AIN2); also elsewhere on the board
MOTOR2_A_OUT: U4.2 (AOUT1); also elsewhere on the board
MOTOR2_B_OUT: U4.4 (AOUT2); also elsewhere on the board
MOTOR2_CTRL1: U4.16 (AIN1); also elsewhere on the board
MOTOR2_CTRL2: U4.15 (AIN2); also elsewhere on the board
MOTOR3_A_OUT: U7.7 (BOUT1); also elsewhere on the board
MOTOR3_B_OUT: U7.5 (BOUT2); also elsewhere on the board
MOTOR3_CTRL1: U7.9 (BIN1); also elsewhere on the board
MOTOR3_CTRL2: U7.10 (BIN2); also elsewhere on the board
MOTOR4_A_OUT: U4.7 (BOUT1); also elsewhere on the board
MOTOR4_B_OUT: U4.5 (BOUT2); also elsewhere on the board
MOTOR4_CTRL1: U4.9 (BIN1); also elsewhere on the board
MOTOR4_CTRL2: U4.10 (BIN2); also elsewhere on the board
unnamed: L4.1, L5.2
unnamed: R22.2, R27.1
unnamed: R26.1, R31.2
unnamed: R28.1, R35.2
unnamed: R29.1, R32.1, U4.3 (AISEN)
unnamed: R35.1, U4.6 (BISEN)
unnamed: C4.2, U4.11 (VCP)
unnamed: C2.2, U4.14 (VINT)
unnamed: C14.1, U6.1 (VINA), U6.12 (EN), U6.13 (PS/SYNC)
unnamed: R23.2, R24.1, U6.3 (FB)
unnamed: L4.2, U6.8 (L1)
unnamed: L5.1, U6.6 (L2)
unnamed: R25.2, U6.14 (PG)
unnamed: R33.1, R36.1, U7.3 (AISEN)
unnamed: R31.1, U7.6 (BISEN)
unnamed: C8.2, U7.11 (VCP)
unnamed: C17.1, U7.14 (VINT)
unnamed: C22.1, U8.1 (VINA), U8.12 (EN), U8.13 (PS/SYNC)
unnamed: R27.2, R30.1, U8.3 (FB)
unnamed: L6.2, U8.8 (L1)
unnamed: L6.1, U8.6 (L2)
unnamed: R34.2, U8.14 (PG)

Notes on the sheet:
Control for MOTOR3 and MOTOR4
Control for MOTOR1 and MOTOR2
MOTOR1 and MOTOR2 need to operate at 200mA, so we'll current-limit at 250mA MOROR3 and MOTOR4 need to operate at 500mA, so we'll current-limit to 600mA We've only got 1ohm and 0.1ohm resistors to work with without incurring, extended feed, so we'll have to settle for 400mA and 1A limit respectively.

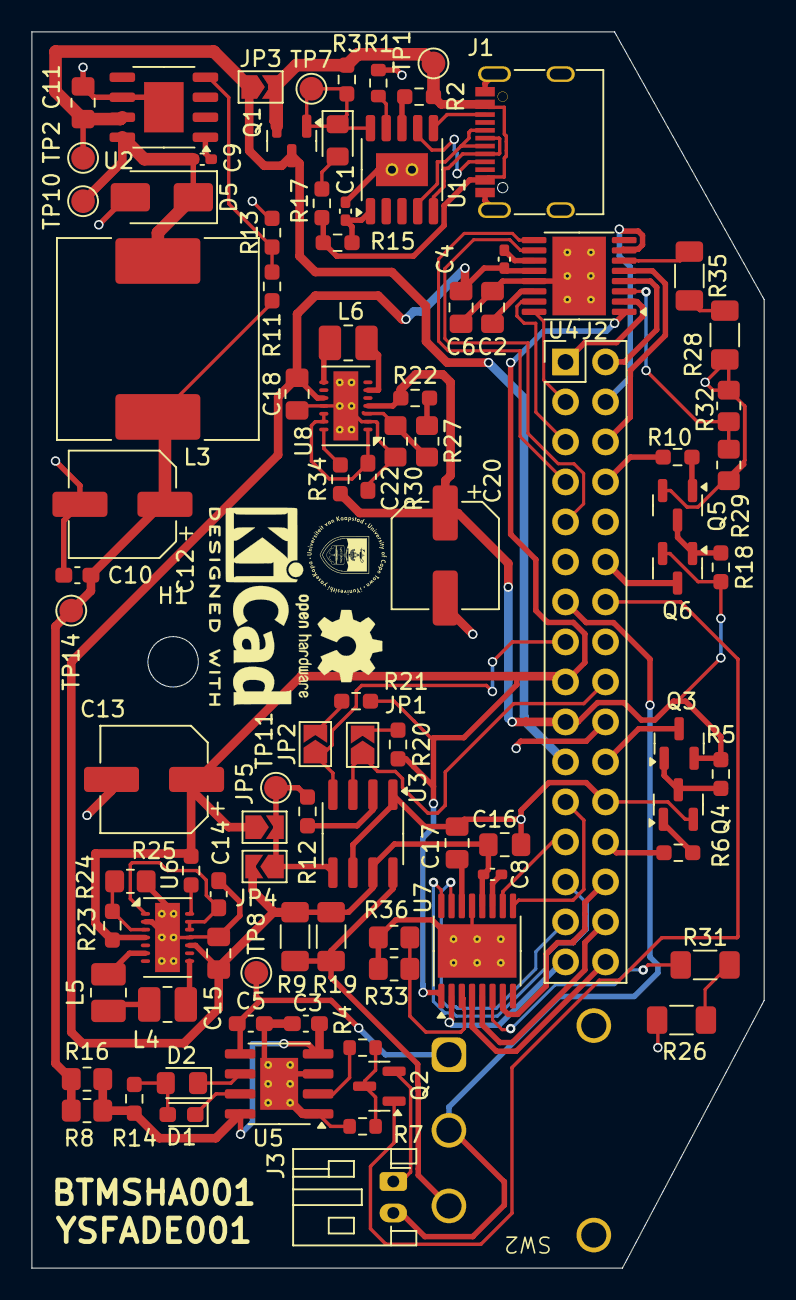
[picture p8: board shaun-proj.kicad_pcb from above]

Board: 2 copper layers, 46.5 x 78.5 mm, 94 parts (0 on the bottom side), 81 nets.

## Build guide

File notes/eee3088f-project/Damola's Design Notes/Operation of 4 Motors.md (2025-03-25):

## Instructions:
Operate up to 4 motors bidirectionally with the pins available to you (listed in the power pinout table). You will need to control $2\times$ brushed DC motors which could each draw $200mA$ at the highest voltage of a 1S1P battery (the battery is further specified in the battery section). The other $2\times$ motors are for the auxiliary connection and need to operate $500mA$ each.

## Breakdown:
- There are 4 motors I need to work with. Let's call them Motor A, Motor B, Motor C and Motor D.
- All 4 motors need to be able to turn bidirectionally. H-Bridge circuit maybe?
- The number of pins I have available to control this function is limited. Need to check that out to take note of the number of available pins as well at their positions.
- 2 brushed DC motors (Motor A & B) that can _each_ draw $200mA$ at the highest voltage of a 1S1P battery.
- 2 motors (Motor C and D. Not sure if they also have to be brushed DC motors) that operate at $500mA$ each.

## Thoughts and findings:
- T
- The **highest voltage** of a fully charged lithium-ion cell in a 1S configuration is **4.2V**.

## Decisions:
- Using the

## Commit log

2025-03-17 add shaun kicad project
    [shaun-proj.kicad_pcb, shaun-proj.kicad_sch]
2025-03-18 v regulator notes
2025-03-21 9v usb req
    [shaun-proj.kicad_sch]
2025-03-21 finish 1st draft of battery charging imlementation
    [shaun-proj.kicad_sch]
2025-03-21 Made a folder called damola-proj, which contains the KiCad gerber files. Nothing currently on the files.
    [untitled.kicad_pcb]
2025-03-22 improve battery charging circuit greatly, start with battery output monitoring
    [shaun-proj.kicad_sch]
2025-03-22 Made a few note about the motor task
2025-03-22 Deleted the previous KiCad files
    [untitled.kicad_pcb]
2025-03-22 add connectors and stuff
    [shaun-proj.kicad_sch]
2025-03-23 bucnh of improvements and additions, can't remember
    [shaun-proj.kicad_sch]
2025-03-25 switching, improvements, PCB start
    [BOM-shaun-proj.csv, junk.kicad_sch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]
2025-03-25 major improvements, components layout + pcb, parts, tests, i2c stuff, ++
    [BOM-shaun-proj.csv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]
2025-03-25 innocuous change
    [shaun-proj.kicad_sch]
2025-03-25 Did my schematic, added some but not all the footprints. Added all the relevant datasheets.
    [damola-proj.kicad_pcb, damola-proj.kicad_sch]
2025-03-26 combine schematics, optimize damolas schematic, fixes, part assignment, pcb population
    [BOM-shaun-proj.csv, damola-proj.kicad_sch, damola.kicad_sch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]
2025-03-26 Added my custom footprint
2025-03-26 Added the symbol for the buck-boost converter
2025-03-27 I think I've added the 'correct' symbol. The PG pin is wrong but it's only one thing that'll have to be changed.
2025-03-28 da board
    [BOM-shaun-proj.csv, damola.kicad_sch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]
2025-04-04 footprint issues
    [shaun-proj-CuBottom.gbr, shaun-proj-CuTop.gbr, shaun-proj-EdgeCuts.gbr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]
2025-04-24 schema improvements, cleanup
    [damola.kicad_sch]
2025-05-12 I believe this should sync my changes
    [damola-proj.kicad_sch, shaun-proj.kicad_sch]
2025-05-14 improved schematic, included more comments
    [damola.kicad_sch, shaun-proj.kicad_sch]
